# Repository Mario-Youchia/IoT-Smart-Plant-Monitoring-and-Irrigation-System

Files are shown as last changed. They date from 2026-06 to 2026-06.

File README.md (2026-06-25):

# IoT Smart Plant Monitoring and Irrigation System

Smart plant monitoring and irrigation system using ESP8266 that can measure temperature, humidity, soil moisture and water level, upload the readings to Firebase Realtime Database, display the live values on an OLED screen and control a water pump automatically or manually from a mobile application.

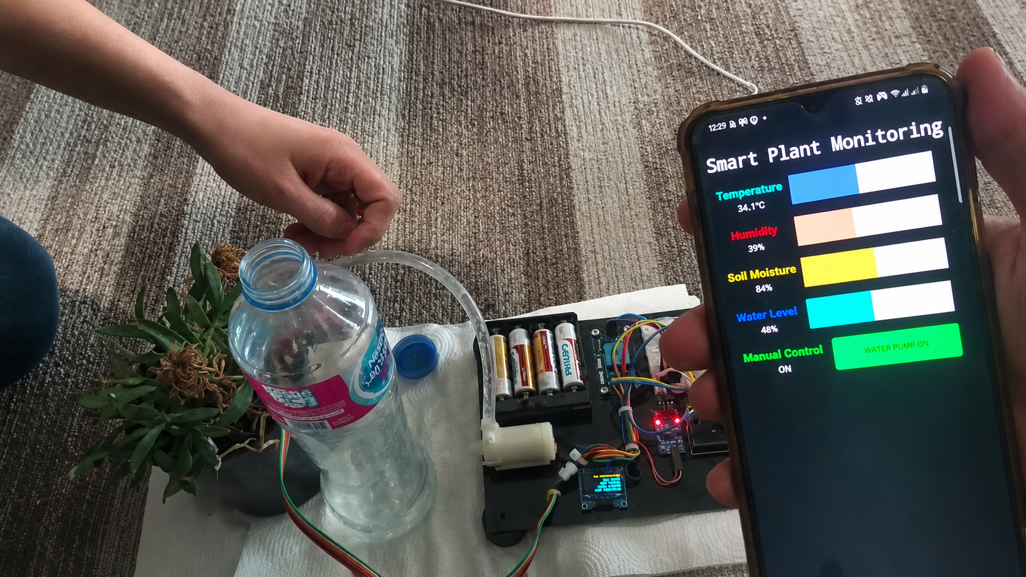
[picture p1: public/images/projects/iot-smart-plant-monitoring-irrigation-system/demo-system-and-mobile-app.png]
System demonstration with mobile app


## Project Links

* [Watch the system demonstration on YouTube](https://youtu.be/aI00_OWCgdE)
* [View and download the CAD assembly on GrabCAD](https://grabcad.com/library/iot-smart-plant-monitoring-and-irrigation-system-1)
* [View the project presentation on Google Drive](https://drive.google.com/file/d/1_8KFbPvdZKp6DIN9-UDTGGExOlGt3kEv/view?usp=sharing)
* [View the project report on Google Drive](https://drive.google.com/file/d/1Z6fiAquu5lFb8KfRN3QRPsXgbrMNaOEP/view?usp=sharing)

## Main Features

- ESP8266 NodeMCU firmware for sensor reading, cloud updates, OLED display output, and pump control.
- DHT11 temperature and humidity reading implemented through timing pulses.
- Soil-moisture and water-level readings through the ESP8266 analog input using a 74HC4051 multiplexer.
- Firebase Realtime Database integration for remote monitoring and manual pump control.
- MIT App Inventor mobile application for live sensor values and manual pump control.
- OLED display for local monitoring.
- Test-case generation and verification for the pump-control decision logic.

## System Overview

The system gathers environmental and plant state readings from multiple sensors. The ESP8266 uses these values to decide if the plant needs to be irrigated. A water-level sensor is used as a master safety condition to prevent the pump from operating when the water level is above the threshold.

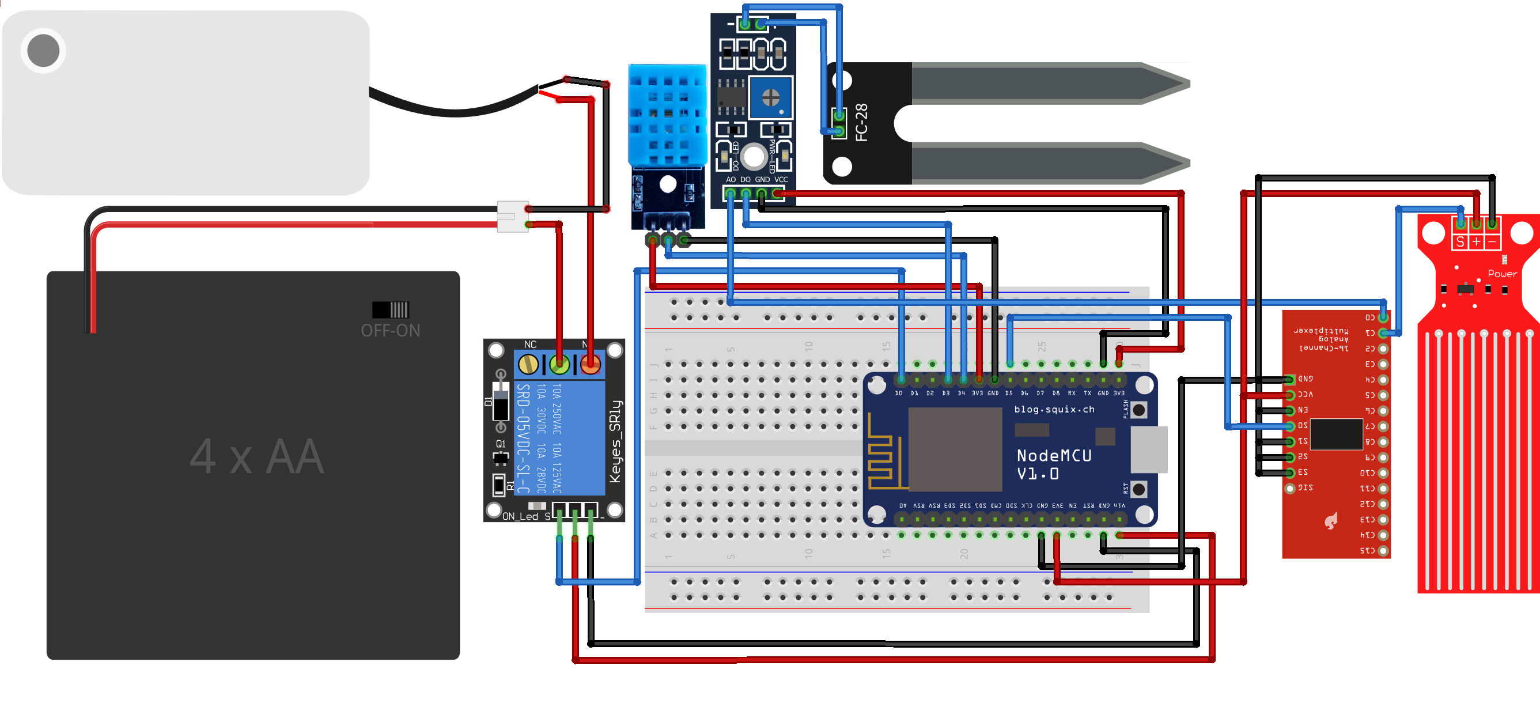
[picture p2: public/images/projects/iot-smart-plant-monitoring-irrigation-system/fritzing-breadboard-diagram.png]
Fritzing circuit diagram


The mobile application reads values from Firebase and can write a manual pump-control signal. The firmware merges this manual command with the automatic control decisions.

A complete demonstration of the working system is available on [YouTube](https://youtu.be/aI00_OWCgdE).

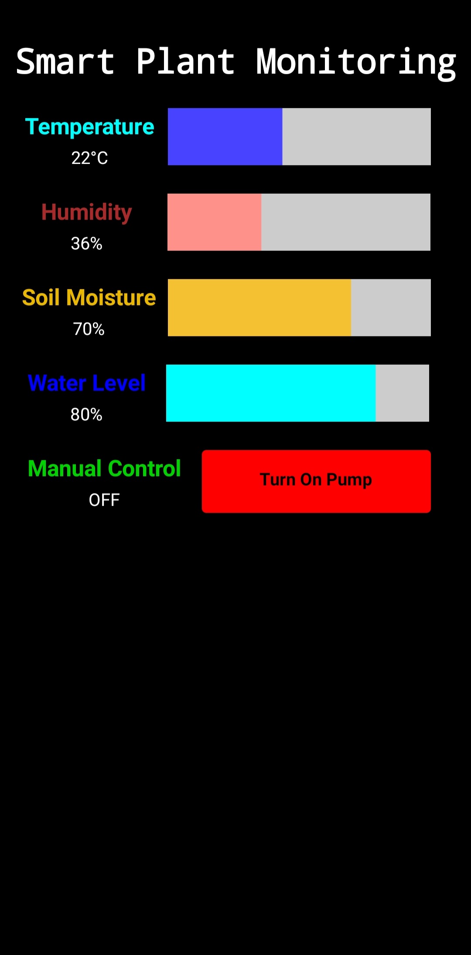
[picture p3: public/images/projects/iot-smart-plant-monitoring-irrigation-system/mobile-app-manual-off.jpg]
Mobile app manual control off


## Hardware and Mechanical Design

The prototype combines the electronics, pump, reservoir, and plant into a single physical setup.

The complete CAD assembly and laser-cut base design are also available on [GrabCAD](https://grabcad.com/library/iot-smart-plant-monitoring-and-irrigation-system-1).

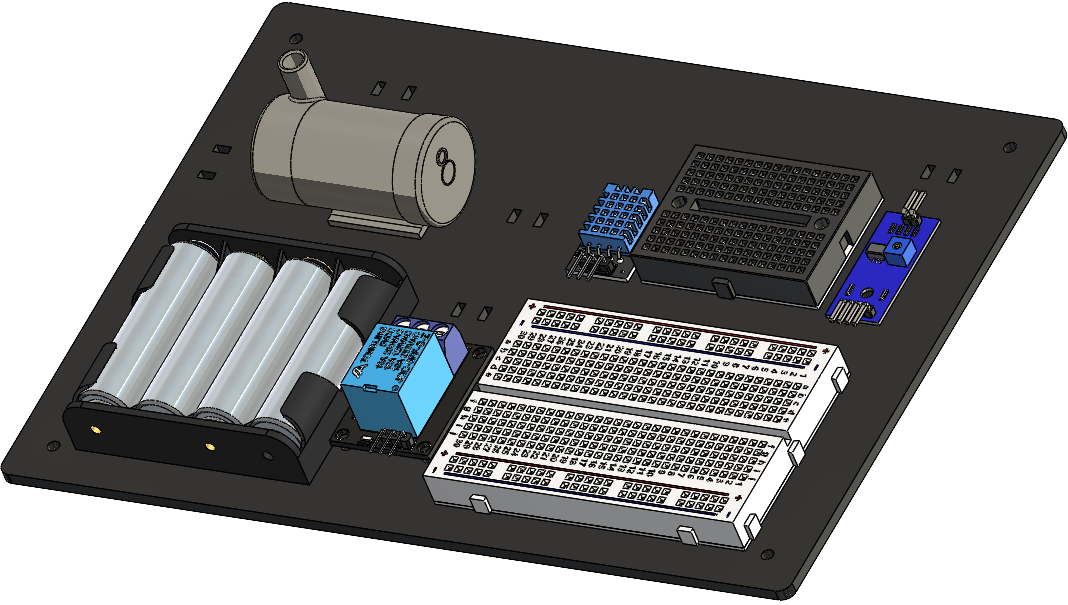
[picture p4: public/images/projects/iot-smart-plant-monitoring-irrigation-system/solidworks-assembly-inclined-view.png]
SolidWorks assembly view


## Control Logic

The pump-control decision is based on four main conditions:

| Signal | Meaning |
|---|---|
| `MasterControl` | Water-level safety condition. The pump is disabled when water is above the threshold. |
| `Decision1` | Soil is dry enough to require watering. |
| `Decision2` | Temperature is high enough to trigger watering. |
| `ManualControl` | User requested pump operation through Firebase/mobile app. |

The pump is only operated when the master water-level condition is satisfied. Then it switches on if the user requests manual irrigation, the soil is dry, or the temperature is high.

## Why a Multiplexer Was Used

The ESP8266 has only one analog input. The project uses a 74HC4051 multiplexer to connect multiple analog sensors to the same input. This avoids adding a second microcontroller and keeps the prototype smaller and less complex.

## Firmware Structure

```text
firmware/
└── SmartPlantMonitoring/
    ├── SmartPlantMonitoring.ino
    ├── helper_functions.h
    ├── helper_functions.cpp
    └── credentials.example.h
```

Create your local credentials file before uploading the firmware:

```bash
cp firmware/SmartPlantMonitoring/credentials.example.h firmware/SmartPlantMonitoring/credentials.h
```

Then edit `credentials.h` with your Wi-Fi and Firebase project values.

## Required Arduino Libraries

Install the following libraries in the Arduino IDE:

- ESP8266 board support package
- Firebase ESP Client
- ESP8266WiFi
- SSD1306Wire / ESP8266 OLED driver
- Wire

## Test-Case Verification

The `tests/` folder contains a Python generator and C++ verification program for the pump-control decision logic.

The generator lists combinations of the water level state, Firebase readiness, signup state, manual command state, soil moisture state, and temperature state. The verifier checks the expected master-control, decision, manual-control, slave-control and pump-status outputs.

## Limitations

- The prototype is a single-plant project, and not suitable in its current form for agricultural deployment, but it can be expanded to be suitable.
- The system depends on Firebase availability for remote monitoring and manual control.

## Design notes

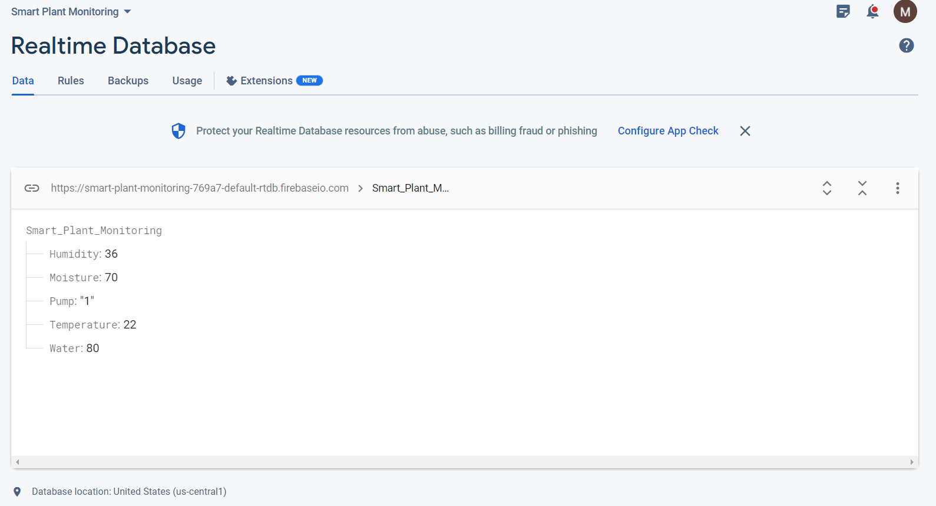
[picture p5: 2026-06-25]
public/images/projects/iot-smart-plant-monitoring-irrigation-system/firebase-realtime-database.png

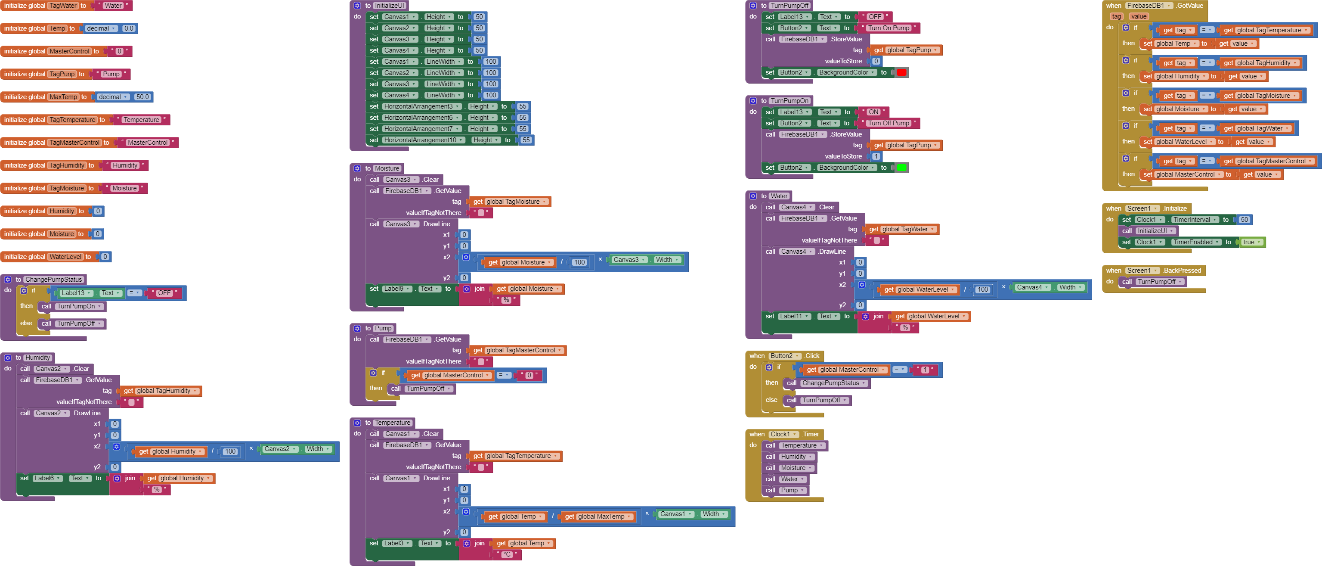
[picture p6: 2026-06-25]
public/images/projects/iot-smart-plant-monitoring-irrigation-system/app-inventor-blocks-final.png

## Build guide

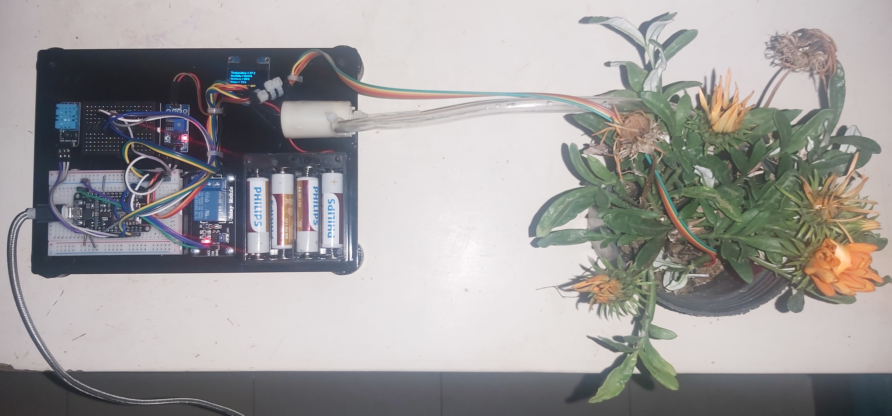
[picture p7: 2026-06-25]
public/images/projects/iot-smart-plant-monitoring-irrigation-system/assembled-prototype-overview.jpg

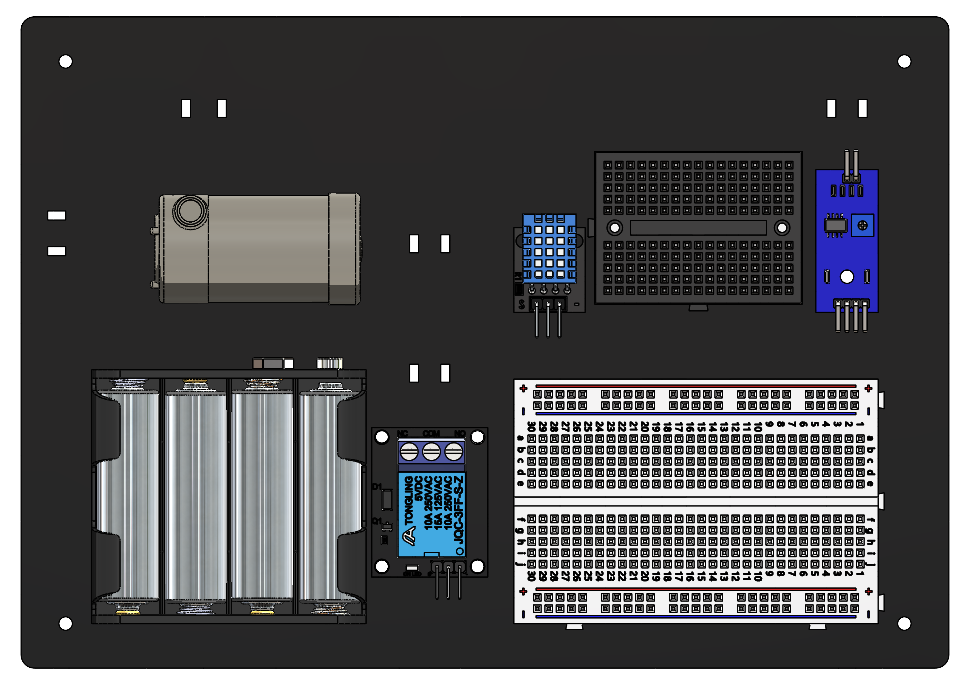
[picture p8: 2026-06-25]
public/images/projects/iot-smart-plant-monitoring-irrigation-system/solidworks-assembly-plan-view.png

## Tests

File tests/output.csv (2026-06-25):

WaterLevel | Firebase_ready | signupok | getString | SoilMoistureSensor | TemperatureSensor | userInput | MasterControlSignal | Decision1 | Decision2 | ManualControl | SlaveControlSignal | PumpStatus
0-599 | 1 | 1 | 1 | 0-749 | 30-50 | 1 | 1 | 0 | 1 | 1 | 1 | 1
0-599 | 1 | 1 | 1 | 0-749 | 30-50 | 0 | 1 | 0 | 1 | 0 | 1 | 1
0-599 | 1 | 1 | 1 | 0-749 | 0-29 | 1 | 1 | 0 | 0 | 1 | 1 | 1
0-599 | 1 | 1 | 1 | 0-749 | 0-29 | 0 | 1 | 0 | 0 | 0 | 0 | 0
0-599 | 1 | 1 | 1 | 750-1024 | 30-50 | 1 | 1 | 1 | 1 | 1 | 1 | 1
0-599 | 1 | 1 | 1 | 750-1024 | 30-50 | 0 | 1 | 1 | 1 | 0 | 1 | 1
0-599 | 1 | 1 | 1 | 750-1024 | 0-29 | 1 | 1 | 1 | 0 | 1 | 1 | 1
0-599 | 1 | 1 | 1 | 750-1024 | 0-29 | 0 | 1 | 1 | 0 | 0 | 1 | 1
0-599 | 1 | 1 | 0 | 0-749 | 30-50 | 1 | 1 | 0 | 1 | 0 | 1 | 1
0-599 | 1 | 1 | 0 | 0-749 | 30-50 | 0 | 1 | 0 | 1 | 0 | 1 | 1
0-599 | 1 | 1 | 0 | 0-749 | 0-29 | 1 | 1 | 0 | 0 | 0 | 0 | 0
0-599 | 1 | 1 | 0 | 0-749 | 0-29 | 0 | 1 | 0 | 0 | 0 | 0 | 0
0-599 | 1 | 1 | 0 | 750-1024 | 30-50 | 1 | 1 | 1 | 1 | 0 | 1 | 1
0-599 | 1 | 1 | 0 | 750-1024 | 30-50 | 0 | 1 | 1 | 1 | 0 | 1 | 1
0-599 | 1 | 1 | 0 | 750-1024 | 0-29 | 1 | 1 | 1 | 0 | 0 | 1 | 1
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

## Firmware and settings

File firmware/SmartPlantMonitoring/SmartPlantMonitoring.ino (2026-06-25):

#include "helper_functions.h"
#include "addons/RTDBHelper.h"
#include "addons/TokenHelper.h"

void setup() {
  Serial.begin(SerialBaudRate);
  initWiFi();
  initFirebase();
  initAnalogSensors();
  initPump();
  initDisplay();
  updateScreen();
}

void loop() {
  Serial.println("********** New Loop **********");
  Decision2 = getDHTData();
  Decision1 = getMoistureData();
  delay(100);
  MasterControl = getWaterData();
  delay(1000);
  controlPump();
  updateFirebase();
  updateScreen();
}

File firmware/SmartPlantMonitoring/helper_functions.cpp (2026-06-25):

#include "helper_functions.h"

bool signupOk = false;
bool Decision1 = false;
bool Decision2 = false;
bool MasterControl = false;  // true means the pump is allowed to respond to control signals.
bool ManualControl = false;
uint16_t Water = 0;
uint16_t Moisture = 0;
float Temperature = 0;
float Humidity = 0;
String PumpStatus = "";
uint8_t data[5];
uint32_t cycles[80];
uint32_t count = 0;

FirebaseData cloud;
FirebaseConfig config;
FirebaseAuth auth;
SSD1306Wire display(0x3c, D2, D1);

void initWiFi() {
  WiFi.mode(WIFI_STA);
  WiFi.begin(WIFI_SSID, WIFI_PASSWORD);
  while (WiFi.status() != WL_CONNECTED) {
    delay(500);
    Serial.print(".");
  }
  onWiFiConnect();
}

void onWiFiConnect() {
  Serial.println("");
  Serial.print("Connected: ");
  Serial.print(WIFI_SSID);
  Serial.println("");
  Serial.print(WiFi.localIP());
  Serial.println("");
}

void initFirebase() {
  config.api_key = FIREBASE_API_KEY;
  config.database_url = FIREBASE_DATABASE_URL;
  Firebase.signUp(&config, &auth, "", "") ? onFirebaseSignUp() : onFirebaseSignUpError();
  Firebase.begin(&config, &auth);
  Firebase.reconnectWiFi(true);
}

void onFirebaseSignUp() {
  signupOk = true;
  Serial.println("OK");
}

void onFirebaseSignUpError() {
  Serial.printf("%s\n", config.signer.signupError.message.c_str());
  Serial.println("Error");
}

void initAnalogSensors() {
  pinMode(MuxSelectPin, OUTPUT);
}

void initPump() {
  digitalWrite(PumpPin, LOW);
  pinMode(PumpPin, OUTPUT);
}

void initDisplay() {
  display.init();
  display.clear();
}

bool getDHTData() {
  delay(1000);
  data[0] = data[1] = data[2] = data[3] = data[4] = 0;

  pinMode(DHTPIN, OUTPUT);
  digitalWrite(DHTPIN, LOW);
  delay(20);

  pinMode(DHTPIN, INPUT_PULLUP);
  delayMicroseconds(50);

  count = 0;
  while (digitalRead(DHTPIN) == LOW && count++ < MaxCount) {}
  if (count >= MaxCount) return false;

  count = 0;
  while (digitalRead(DHTPIN) == HIGH && count++ < MaxCount) {}
  if (count >= MaxCount) return false;

  for (int i = 0; i < 80; i += 2) {
    count = 0;
    while (digitalRead(DHTPIN) == LOW && ++count) {}
    cycles[i] = count;

    count = 0;
    while (digitalRead(DHTPIN) == HIGH && ++count) {}
    cycles[i + 1] = count;
  }

  for (int i = 0; i < 40; ++i) {
    uint32_t lowCycles = cycles[2 * i];
    uint32_t highCycles = cycles[2 * i + 1];
    data[i / 8] <<= 1;
    if (highCycles > lowCycles) data[i / 8] |= 1;
  }

  if (data[4] == ((data[0] + data[1] + data[2] + data[3]) & 0xFF)) {
    Humidity = data[0] + data[1] * 0.1;
    Temperature = data[2] + (data[3] & 0x0f) * 0.1;
  }

  Serial.printf("Humidity = %.1f%%\nTemperature = %.1f°C\n", Humidity, Temperature);
  return (Temperature >= TempHigh);
}

bool getMoistureData() {
  digitalWrite(MuxSelectPin, 0);
  Moisture = analogRead(AnalogPin);
  Serial.printf("Moisture Level: %.2f%%\n%s\n",
                Moisture * 100.0 / 1024.0,
                (Moisture < Moisture_Wet) ? "Status: Soil is too wet" :
                (Moisture < Moisture_Dry) ? "Status: Soil moisture is perfect" :
                                           "Status: Soil is too dry - time to water!");
  return (Moisture >= Moisture_Dry);
}

bool getWaterData() {
  digitalWrite(MuxSelectPin, 1);
  Water = analogRead(AnalogPin);
  Serial.printf("Water Level: %.2f%%\nStatus: Water level is %s\n",
                Water * 100.0 / 1024.0,
                (Water < Water_Low) ? "LOW" : (Water < Water_High) ? "MEDIUM" : "HIGH");
  return (Water < Water_High);
}

void controlPump() {
  if (MasterControl) {
    if (Firebase.ready() && signupOk) {
      Firebase.RTDB.setString(&cloud, MASTERCONTROL_URL, "1");
      PumpStatus = Firebase.RTDB.getString(&cloud, PUMP_URL) ? cloud.stringData() : "";
    }

    ManualControl = (PumpStatus == "1");
    digitalWrite(PumpPin, (PumpStatus == "1" || Decision1 || Decision2) ? HIGH : LOW);
  } else {
    Firebase.RTDB.setString(&cloud, MASTERCONTROL_URL, "0");
    Firebase.RTDB.setString(&cloud, PUMP_URL, "0");
    digitalWrite(PumpPin, LOW);
    ManualControl = false;
    PumpStatus = "0";
  }
}

void updateFirebase() {
  Firebase.RTDB.setFloat(&cloud, TEMPERATURE_URL, Temperature);
  Firebase.RTDB.setFloat(&cloud, HUMIDITY_URL, Humidity);
  Firebase.RTDB.setInt(&cloud, WATER_URL, Water * 100 / 1024);
  Firebase.RTDB.setInt(&cloud, MOISTURE_URL, Moisture * 100 / 1024);
}

void updateScreen() {
  display.clear();
  display.setTextAlignment(TEXT_ALIGN_LEFT);
  display.setFont(ArialMT_Plain_10);
  display.drawString(0, 0, "Temperature = " + String(Temperature, 1) + String("°C"));
  display.drawString(0, 12, "Humidity = " + String(Humidity, 1) + "%");
  display.drawString(0, 24, "Moisture = " + String(Moisture * 100 / 1024) + "%");
  display.drawString(0, 36, "Water = " + String(Water * 100 / 1024) + "%");
  ManualControl ? display.drawString(0, 48, "Manual Control: ON") : display.drawString(0, 48, "Manual Control: OFF");
  display.display();
}
